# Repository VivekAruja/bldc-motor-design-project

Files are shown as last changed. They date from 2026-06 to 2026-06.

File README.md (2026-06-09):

# Brushless DC Motor Design Project

## Overview

This project presents the design, CAD modelling, 3D printing, winding, assembly, and testing of a small brushless DC motor (BLDC). The motor was designed as a radial flux, three phase, six slot/eight pole outrunner BLDC motor using SOLIDWORKS, 3D printed parts, permanent magnets, copper windings, and an electronic speed controller.

The goal of the project was to complete the full motor design workflow from theory to physical implementation. This included selecting motor specifications, performing design calculations, modelling the stator and rotor in SOLIDWORKS, exporting STL files, assembling the motor, winding the stator, and testing the final prototype.

## Final Technical Report

The full technical report is available here:

[Brushless DC Motor Design Project Report](report/BLDC_Motor_Project_Report.pdf)

## Project Motivation

Brushless DC motors are widely used in electric vehicles, drones, robotics, fans, pumps, and other electromechanical systems because they offer high efficiency, low maintenance, and reliable operation compared with brushed DC motors.

This project was built to answer one main question:

**Can a small custom BLDC motor be designed, fabricated, wound, assembled, and tested using 3D printed components and available lab materials?**

The project demonstrates the complete workflow:

Motor specifications
→ analytical calculations
→ SOLIDWORKS CAD modelling
→ STL export
→ 3D printing
→ stator winding
→ physical assembly
→ ESC testing
→ performance evaluation

## Tools and Technologies

* SOLIDWORKS
* 3D printing
* STL modelling
* BLDC motor design
* Electronic speed controller testing
* Copper winding
* Neodymium magnets
  
## Repository Structure

```text
bldc-motor-design-project/
│
├── assembly/
│   └── full motor assembly files and screenshots
│
├── images/
│   └── project images used for the README and report
│
├── parts/
│   └── SOLIDWORKS part files
│
├── report/
│   ├── main.tex
│   ├── BLDC_Motor_Project_Report.pdf
│   └── figures/
│
├── stl_exports/
│   ├── Rotor.STL
│   ├── StatorBottom.STL
│   └── StatorTop.STL
│
└── README.md
```

## Design Objectives

The main design objectives were:

* Design a small BLDC motor within the required size constraint.
* Use a six slot/eight pole electromagnetic layout.
* Create a radial flux outrunner motor design.
* Model the stator and rotor in SOLIDWORKS.
* Export the rotor and stator parts as STL files for 3D printing.
* Wind the stator using a three phase ABC winding scheme.
* Assemble the motor using the shaft, bearings, magnets, rotor, stator, and test base.
* Test the motor using an electronic speed controller.

## Motor Specifications

| Parameter | Value |
| --- | --- |
| Motor type | Radial flux outrunner BLDC |
| Number of phases | 3 |
| Stator teeth | 6 |
| Rotor poles / magnets | 8 |
| Winding scheme | ABC |
| Connection type | Wye / Star |
| Rated torque | 0.075 N·m |
| Rated speed | 2000 RPM |
| Rated voltage | 12 V |
| Estimated rated current | 1.31 A |
| Target air gap | 2 mm |
| Stator outer diameter | 61 mm |
| Rotor inner diameter | 65 mm |
| Rotor outer diameter | 71 mm |
| Axial stack length | 30 mm |
| Calculated turns per tooth | 17 turns |
| Actual turns per tooth | 8 turns |

## CAD Design

The motor was modelled in SOLIDWORKS using separate stator and rotor parts. The design focused on motor geometry, shaft alignment, bearing support, magnet placement, 3D printability, and assembly fit.

### Stator Design

The stator was designed with six teeth for a three phase winding layout. The stator includes a central shaft hole, bearing pockets, and a square mounting boss to fit the course test stand.

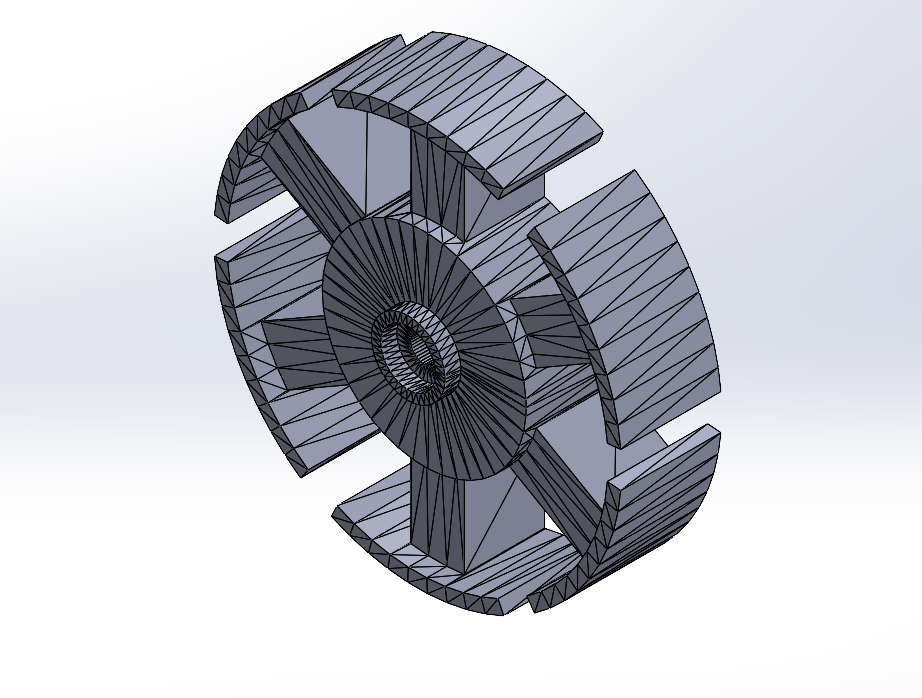
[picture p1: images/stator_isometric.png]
Stator CAD Model


### Rotor Design

The rotor was designed as an outrunner can with eight internal magnet pockets. The rotor surrounds the stator, allowing the permanent magnets to rotate around the wound stator teeth.

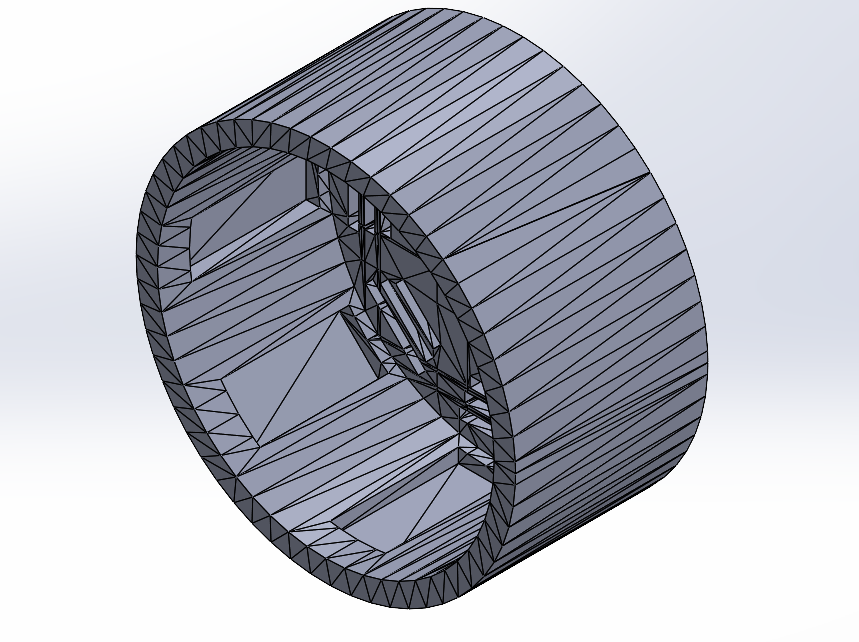
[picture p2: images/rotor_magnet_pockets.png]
Rotor Magnet Pockets


### Full Assembly

The full assembly was created in SOLIDWORKS to verify that the rotor and stator were aligned correctly and that the final geometry matched the intended outrunner BLDC design.

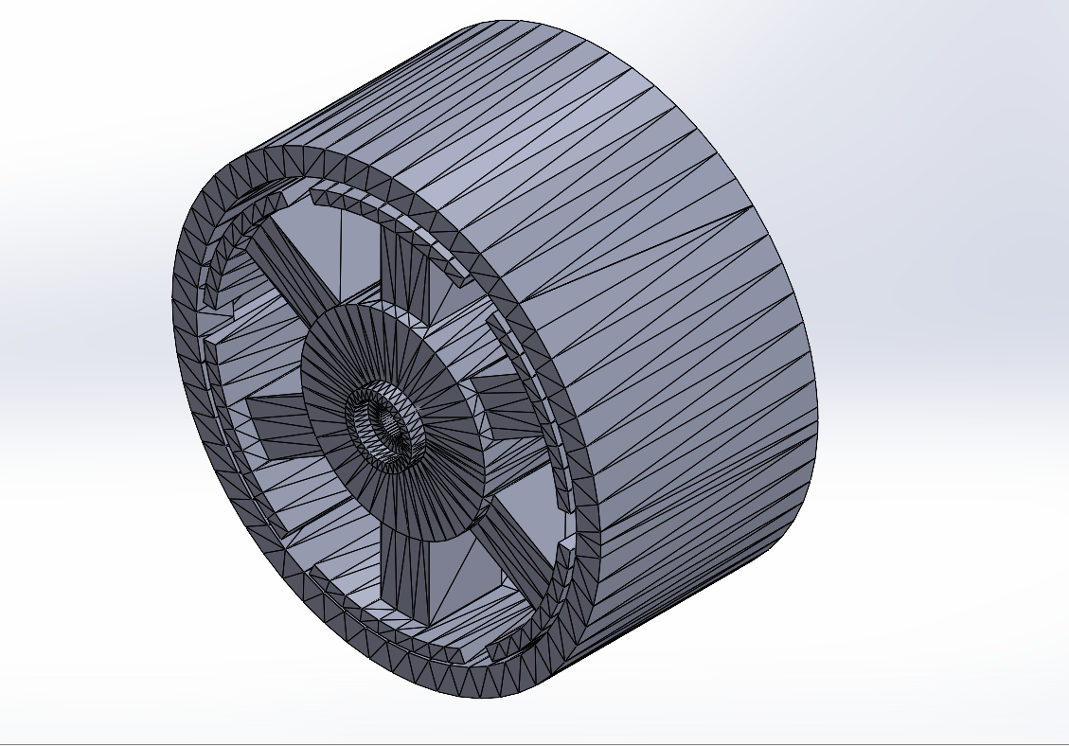
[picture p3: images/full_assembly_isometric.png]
Full BLDC Motor Assembly


## 3D Printing and Fabrication

The stator and rotor parts were exported as STL files and 3D printed. The exported files included:

* `Rotor.STL`
* `StatorBottom.STL`
* `StatorTop.STL`

The stator was split into top and bottom printed sections to improve manufacturability and simplify assembly around the shaft and bearing features. After printing, the parts were checked for fit, clearance, and alignment.

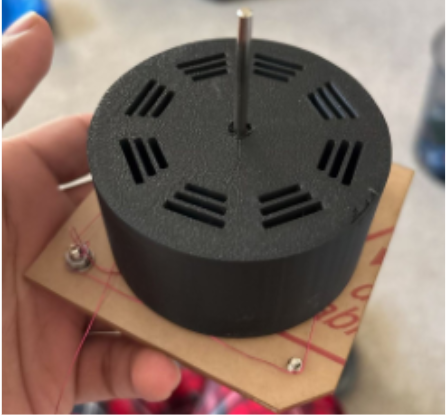
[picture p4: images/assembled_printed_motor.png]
Assembled 3D Printed Motor


## Winding and Assembly

The stator was wound using an ABC three phase winding arrangement with a wye connection. The calculated design required approximately 17 turns per tooth, but the final physical motor used 8 turns per tooth because the available wire gauge and slot space limited the number of turns that could be physically wound.

Eight N52 neodymium magnets were inserted into the rotor pockets to create the eight pole rotor field. The printed stator, rotor, shaft, bearings, magnets, and test base were then assembled into the final motor prototype.

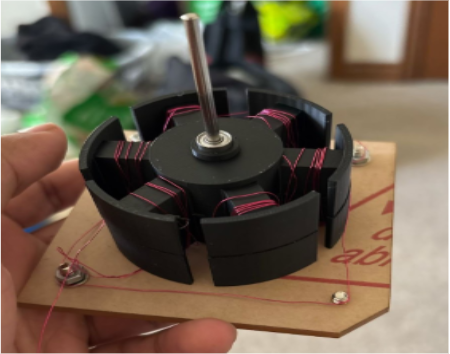
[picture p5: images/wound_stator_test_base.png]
Wound Stator Assembly


## Design Calculations

The main design calculations included:

* Angular velocity
* Mechanical output power
* Estimated rated current
* Flux density at the stator surface
* Number of teeth per phase
* Required winding turns per tooth

The rated speed was selected as 2000 RPM. The angular velocity was calculated as:

```text
ω = 2πN / 60
ω = 209.4 rad/s
```

The mechanical power was calculated using:

```text
P = τω
P = 0.075 × 209.4
P = 15.7 W
```

The estimated rated current was calculated using:

```text
I = P / V
I = 15.7 / 12
I = 1.31 A
```

The calculated number of turns per tooth was approximately 17 turns. The final motor used 8 turns per tooth due to physical slot space and wire gauge constraints.

## Testing Methodology

The motor was tested using an electronic speed controller, power supply, and control input. Before testing, the following checks were performed:

* Rotor clearance around the stator
* Shaft and bearing alignment
* Magnet placement
* Winding condition
* Phase wire connections
* Supply voltage limit

The motor response was evaluated based on whether it could start, whether it could sustain rotation, whether the rotor rubbed against the stator, and whether the ESC appeared to drive the motor phases correctly.

## Results

The final motor fit within the required size constraint and was successfully assembled using the 3D printed rotor and stator components. The motor responded to the electronic speed controller and produced slight rotational motion, but it did not sustain continuous independent rotation.

The main successful outcomes were:

* Completed BLDC motor design calculations
* Created stator and rotor CAD models in SOLIDWORKS
* Exported printable STL files
* 3D printed the motor components
* Wound the stator using a three phase winding layout
* Assembled the motor with shaft, bearings, rotor, stator, and magnets
* Tested the motor with an ESC

## Key Findings

The main findings were:

* The six slot/eight pole outrunner layout was appropriate for the project requirements.
* The motor geometry was successfully modelled and assembled.
* The physical prototype fit within the required size envelope.
* The actual air gap was larger than the design target, reducing magnetic coupling.
* The final winding count was lower than the calculated value because of slot space and wire gauge limitations.
* Mechanical friction and alignment issues reduced the available starting torque.
* Correct calculations alone do not guarantee strong physical performance because manufacturing tolerances and assembly quality strongly affect motor behaviour.

## Limitations

This project had several limitations:

* The stator and rotor were 3D printed using plastic rather than laminated ferromagnetic steel.
* The actual air gap was larger than the target design value.
* The motor used 8 turns per tooth instead of the calculated 17 turns per tooth.
* Magnet placement and winding were completed manually.
* Testing was mainly observational.
* The project did not include quantitative measurements of torque, no load speed, phase current, back EMF, or efficiency.

## Future Work

Future improvements could include:

* Reducing the rotor stator air gap.
* Redesigning the stator slots to allow more copper turns.
* Using thinner magnet wire to reach the calculated winding count.
* Improving magnet pocket tolerances and magnet retention.
* Improving shaft and bearing alignment.
* Reducing mechanical friction.
* Measuring phase resistance, current, no load speed, back EMF, torque, and efficiency.
* Comparing the 3D printed prototype with a design using laminated steel stator material.

## Lessons Learned

This project showed that BLDC motor design is not only a calculation problem. Physical performance depends heavily on manufacturing tolerance, winding feasibility, air gap control, magnet placement, bearing alignment, and assembly quality.

The project was successful as a full engineering design exercise because it connected theory, CAD modelling, fabrication, winding, assembly, testing, and performance analysis into one complete electromechanical system.

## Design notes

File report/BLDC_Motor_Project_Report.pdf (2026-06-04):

## Brushless DC Motor Design Project

Design, CAD Modelling, 3D Printing, Winding, Assembly, and Testing of a Low Power BLDC Motor

Vivek Aruja

December 10, 2025

Abstract

This project covers the design, modelling, fabrication, winding, assembly, and testing of a small brushless DC motor. The objective was to design a radial flux, three phase, six slot/eight pole outrunner BLDC motor that satisfied the course size and electrical constraints and demonstrated the full motor design workflow from calculations to physical testing. The motor targets a rated torque of 0.075 N ∗ m, a rated speed of 2000 RPM, a rated voltage of 12 V, and an estimated rated current of 1.31 A. The six slot/eight pole electromagnetic layout avoids a one to one teeth to poles relationship to reduce cogging.

The design process began with motor specification selection, analytical calculations, and SOLIDWORKS modelling. The stator was modelled with a 61 mm outer diameter, six teeth, a central shaft hole, bearing pockets, and a square mounting boss for the test stand. The rotor was modelled as an outrunner can with a 65 mm inner diameter, a 71 mm outer diameter, eight magnet pockets, a shaft clearance hub, and ventilation openings. Both files were exported as STL files and 3D printed. After fabrication, the stator was wound using an ABC winding scheme in a wye connection. The calculated design required approximately 17 turns per tooth; the final physical motor used 8 turns per tooth because slot space and wire gauge constraints prevented achieving the full count.

Testing confirmed that the motor responded to the electronic speed controller and produced slight rotational motion, but the motor did not sustain continuous independent rotation. The main limiting factors were an actual air gap larger than the design target, fewer winding turns than calculated, magnet placement inconsistencies, and mechanical friction from the shaft and bearings. The project completed the full process of designing and building a custom BLDC motor and exposed the practical gap between theoretical motor design and physical electromechanical construction.

## Contents

1 | Introduction | 3
2 | Technical Background | 4
3 | Design Requirements and Constraints | 5
4 | Selected Design Parameters | 6
5 | Design Calculations | 7
6 | CAD Design | 10
7 | 3D Printing and Fabrication | 14
8 | Winding and Motor Assembly | 15
9 | Testing Methodology | 17
10 Results | 18
11 Discussion | 19
12 Limitations | 20
13 Future Work | 20
14 Conclusion | 21
References | 22

### 1 Introduction

Brushless DC motors convert electrical energy into mechanical rotation using permanent magnets, stator windings, and electronic commutation. A BLDC motor uses no brushes or mechanical commutator. An electronic speed controller energizes the motor windings by switching motor phases in sequence. A typical three phase BLDC motor achieves improved reliability, lower maintenance, reduced sparking, and better efficiency compared with brushed motor designs.

The objective of this project was to design and build a small BLDC motor that satisfied the course requirements and remained manufacturable using 3D printed parts and available lab components. The motor had to fit within the specified physical size envelope and use the provided shaft, bearings, magnets, copper wire, and test stand.

A radial flux, three phase, six slot/eight pole outrunner BLDC motor was selected. The outrunner layout places the rotor around the stator, increasing the effective rotating radius and improving low speed torque. The six slot/eight pole combination avoids a one to one relationship between stator teeth and rotor poles, which reduces cogging and prevents repeated full alignment between the rotor magnets and stator teeth.

The project followed the engineering workflow below:

Specification selection → analytical calculations → CAD modelling → STL export → 3D printing → winding → assembly → ESC testing

The main design goals were to:

- Design a motor that fits within the 74 mm × 74 mm × 44 mm size constraint.
- Use a six slot/eight pole electromagnetic layout.
- Calculate a realistic number of winding turns per tooth.
- Create manufacturable stator and rotor models in SOLIDWORKS.
- Export STL files suitable for 3D printing.
- Assemble the motor using lab provided shaft, bearings, magnets, and copper wire.
- Test the motor using an electronic speed controller.

### 2 Technical Background

### 2.1 BLDC Motor Operation

A brushless DC motor consists of a stationary stator and a rotating rotor. The stator carries wound copper coils and the rotor carries permanent magnets. Current flowing through the stator windings produces magnetic fields that interact with the rotor magnets and generate torque.

Since a BLDC motor contains no brushes, phase switching must be performed electronically. An electronic speed controller energizes selected motor phases in a controlled sequence. In a three phase BLDC motor, two phases carry current at a time and the third phase floats or is monitored depending on the control strategy. This creates a rotating magnetic field that pulls the rotor into motion.

### 2.2 Outrunner Motor Layout

In an outrunner BLDC motor, the rotor forms an outer rotating shell around the stationary stator. The permanent magnets attach to the inside surface of the rotor and the copper windings sit around the stator teeth. This configuration increases the radius at which magnetic force is applied, improving torque production at low to moderate speeds.

The selected motor uses a radial flux outrunner layout. Magnetic flux crosses the radial air gap between the rotor magnets and stator teeth. The air gap is a critical design parameter because increasing the distance between magnets and windings reduces the magnetic field acting on the stator teeth.

### 2.3 Slots, Teeth, Poles, and Cogging

The stator teeth provide the locations for winding the copper coils. The rotor poles correspond to the permanent magnets installed around the rotor. The selected design used six stator teeth and eight rotor poles.

The teeth to poles ratio is:

Ts : Pr = 6 : 8 | (1)

This ratio is not one to one because equal stator to rotor alignment increases cogging and makes the motor startup more difficult. The six slot/eight pole layout ensures the teeth and magnets do not repeatedly align in a symmetrical locking position.

### 3 Design Requirements and Constraints

The motor design was constrained by course requirements and practical manufacturing limits.

### 3.1 Electrical Requirements

The electrical design targets the following values:

- Rated voltage: 12 V
- Rated torque: 0.075 N ∗ m
- Rated speed: 2000 RPM
- Estimated current: 1.31 A
- Three phase winding
- Wye connection
- Compatibility with an electronic speed controller

A wye connection reduces the current per phase compared with a delta connection, making the design more suitable for the available wire and course testing setup.

### 3.2 Mechanical Requirements

The mechanical design satisfies the following requirements:

- Fits within a 74 mm × 74 mm × 44 mm bounding box.
- Uses 3D printed stator and rotor components.
- Fits the provided shaft and bearing geometry.
- Fits the course test stand.
- Provides clearance between the rotating rotor and stationary stator.
- Provides sufficient slot space for the windings.
- Allows magnet pockets to hold the rotor magnets securely.

### 3.3 Manufacturing Requirements

The stator and rotor were exported as STL files for 3D printing. The design therefore accounts for printability, tolerances, flat surfaces, support requirements, and clearance for post print assembly.

### 4 Selected Design Parameters

Table 1 summarizes the main motor parameters used in the design.

Table 1: Selected BLDC motor design parameters.

Parameter | Value | Reason / Note
Motor type | Radial flux outrunner
| BLDC | Selected for low speed torque
| | potential
Number of phases | 3 | Standard BLDC configuration
Stator teeth | 6 | Multiple of three for three
| | phase winding
Rotor poles / magnets | 8 | Avoids one to one teeth to
| | poles ratio
Winding scheme | ABC | Simple three phase winding
| | layout
Connection type | Wye / Star | Reduces current per phase
Rated torque | 0.075 N ∗ m | Target design torque
Rated speed | 2000 RPM | Moderate speed target
Rated voltage | 12 V | Within low voltage testing
| | range
Magnet grade | N52 neodymium | High residual flux density
Residual flux density, Br | 1.42 T | Used for surface flux estimate
Magnet thickness, t | 0.002 m | Matches rotor pocket depth
Air gap, g | 0.002 m target | Required clearance between
| | rotor and stator
Tooth wall thickness, k | 0.002 m | Plastic wall thickness in flux
| | path
Stator radius, R | 0.0305 m | Used in torque turns calcula-
| | tion
Axial stack length, L | 0.030 m | Selected motor axial length
Calculated turns per tooth | 17 turns | From design equation
Actual turns per tooth | 8 turns | Limited by slot space and wire
| | thickness

### 5 Design Calculations

### 5.1 Angular Velocity

The rated speed was selected as 2000 RPM. Angular velocity was calculated using:

ω =

2πN
60

(2)

where N is the speed in RPM. Substituting the selected speed:

ω =

2π(2000)
60

(3)

ω = 209.4 rad/s | (4)

### 5.2 Mechanical Power

Mechanical output power was calculated using:

Pm = τω | (5)

where τ is torque and ω is angular velocity. At a selected torque of 0.075 N m:

Pm = (0.075)(209.4) | (6)
Pm = 15.7W | (7)

### 5.3 Rated Current

Motor current was estimated from mechanical power and rated voltage:

I =

Pm
V

(8)

Substituting the calculated power and selected voltage:

I =

15.7
12

(9)

I = 1.31 A | (10)

### 5.4 Flux Density at the Stator Surface

The estimated flux density at the stator surface was calculated using:

Ba = Br

t
t + g + k

(11)

where Br is the residual flux density of the magnet, t is magnet thickness, g is the air gap, and k is tooth wall thickness. The selected values were:

Br = 1.42 T, | t = 0.002 m, | g = 0.002 m, | k = 0.002 m | (12)

Therefore:

Ba = 1.42
| | 0.002

0.002 + 0.002 + 0.002
(13)
Ba = 0.473 T | (14)

This equation shows the importance of air gap control. An actual air gap larger than the design value reduces the flux density at the stator surface and lowers the torque the motor can produce.

### 5.5 Number of Teeth per Phase

The number of teeth per phase was calculated using:

n =

Total number of stator teeth
Number of phases | (15)

For six teeth and three phases:

n =

6
3
= 2 | (16)

### 5.6 Turns per Tooth

The required number of turns per tooth was estimated using:

N =

τ
4nBaLRI

(17)

where N is the turns per tooth, τ is torque, n is teeth per phase, Ba is flux density at the stator surface, L is axial stack length, R is stator radius, and I is current.

Substituting the selected values:

N =

0.075
4(2)(0.473)(0.030)(0.0305)(1.31) | (18)
N = 16.5 ≈ 17 turns per tooth | (19)

The calculated value falls within the practical target range of 5 to 50 turns per tooth. The final physical motor used 8 turns per tooth because the available wire gauge and stator slot volume could not accommodate the full calculated number.

### 6 CAD Design

The motor was modelled in SOLIDWORKS using separate stator and rotor parts. The CAD design covers electromagnetic geometry, shaft alignment, bearing support, magnet pockets, and manufacturability through 3D printing.

### 6.1 Stator Design

The stator was designed first. A circle with a radius of 30.5 mm defines the outer radius of the stator teeth, giving a total stator diameter of 61 mm. A smaller concentric circle with a radius of 20 mm defines the inner hub and back iron region.

A single tooth profile was created with radial geometry and a tooth width of approximately 6 mm. A circular pattern with six instances was used to complete the tooth array. The stator was extruded to an axial length of 30 mm.

A square mounting boss of 15 mm × 15 mm was added to the bottom face of the stator. This boss fits the stator into the course test stand and prevents the stator from rotating during motor operation.

A central shaft hole was cut with a radius of 1.5 mm for the 3 mm shaft. Bearing pockets were cut into the stator to locate the bearings and improve shaft alignment.

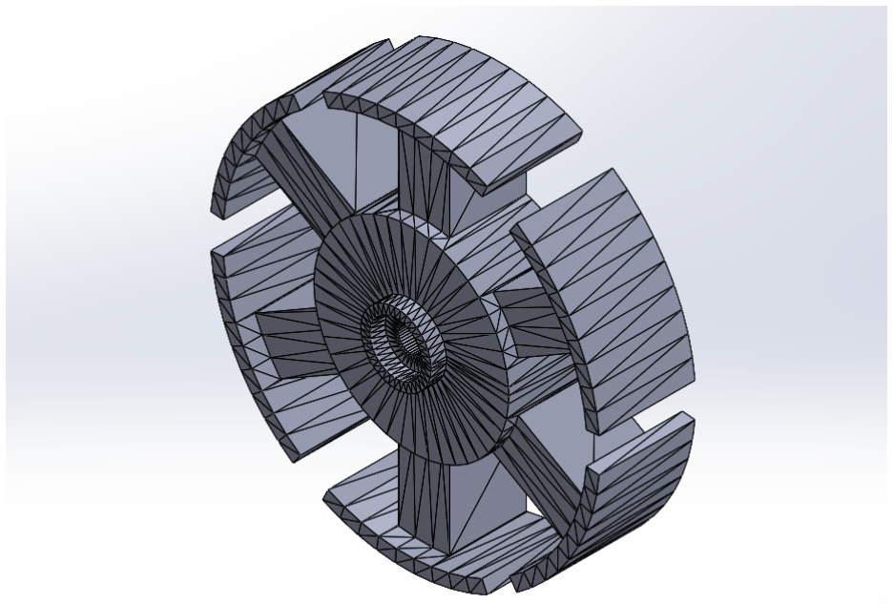
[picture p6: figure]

Figure 1: Isometric view of the six slot outrunner stator CAD model

### 6.2 Rotor Design

The rotor was designed as an outrunner can. To maintain a target air gap of 2 mm, the inside radius of the rotor was set as:

Rrotor, inner = Rstator + g = 30.5 + 2.0 = 32.5 mm | (20)

This gives an inner diameter of 65 mm. The outer radius of the rotor was set to 35.5 mm, giving an outer diameter of 71 mm. The annular rotor wall was extruded to an axial length of 30 mm.

A 3 mm thick cap closes the top of the rotor. Hub cylinders near the shaft region improve strength at the shaft and bearing interface. A shaft clearance hole with radius 1.65 mm passes through the rotor hub to allow a sliding fit.

Eight rectangular magnet pockets were cut into the inside surface of the rotor and patterned around the rotor to create the eight pole layout. The magnet pocket depth matches the magnet thickness of approximately 2 mm. Ventilation slots in the rotor cap reduce mass and allow air flow near the windings.


Figure 2: Rotor CAD model with eight internal magnet pockets

### 6.3 SOLIDWORKS Assembly

After modelling the individual parts, a full assembly was created in SOLIDWORKS. The stator bottom, stator top, and rotor were inserted into a SOLIDWORKS assembly file. The stator components were aligned to form the complete stationary structure and the rotor was positioned concentrically around the stator to represent the final outrunner motor geometry.

The assembly confirmed the relative position of the rotor and stator and produced documentation screenshots for the final report. Because the available geometry was based on STL mesh files, the assembly served as a visual and documentation model rather than a fully parametric SOLIDWORKS assembly.

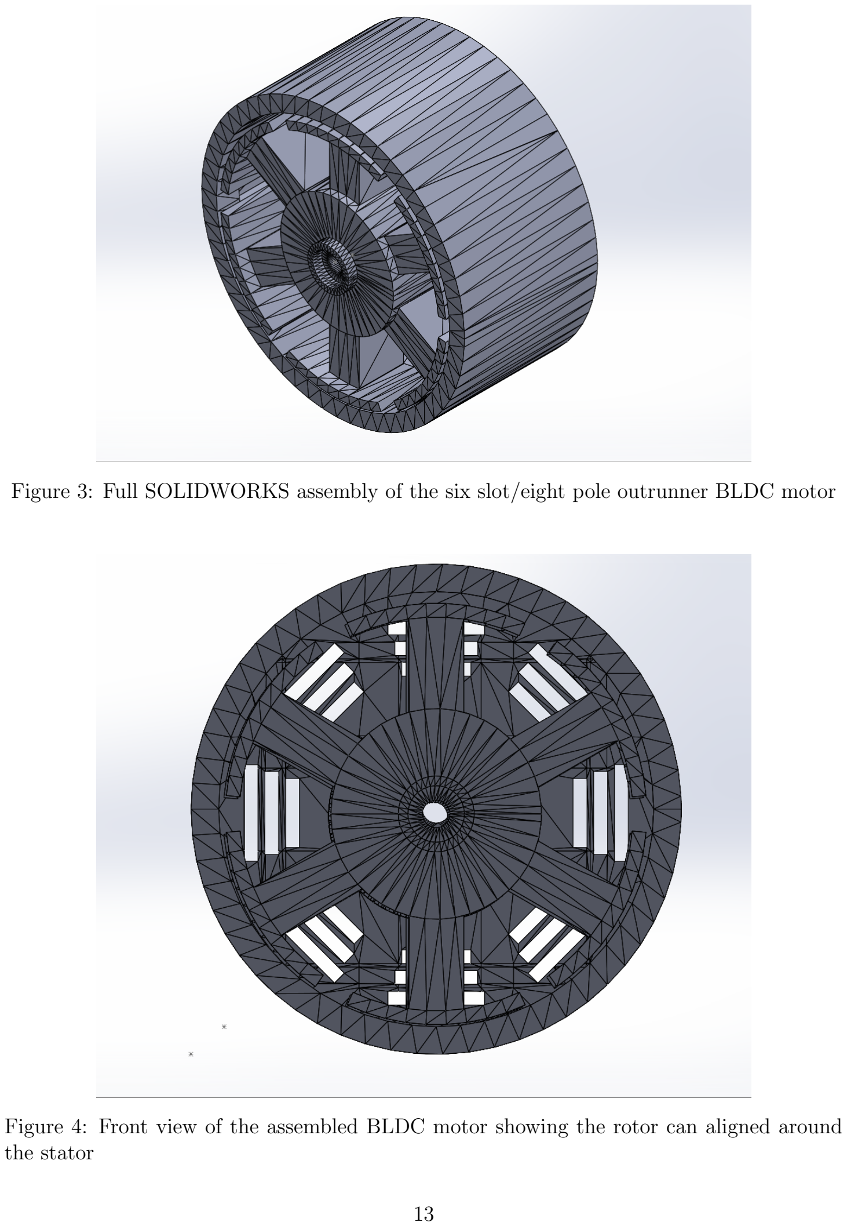
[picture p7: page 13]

Figure 3: Full SOLIDWORKS assembly of the six slot/eight pole outrunner BLDC motor

Figure 4: Front view of the assembled BLDC motor showing the rotor can aligned around the stator

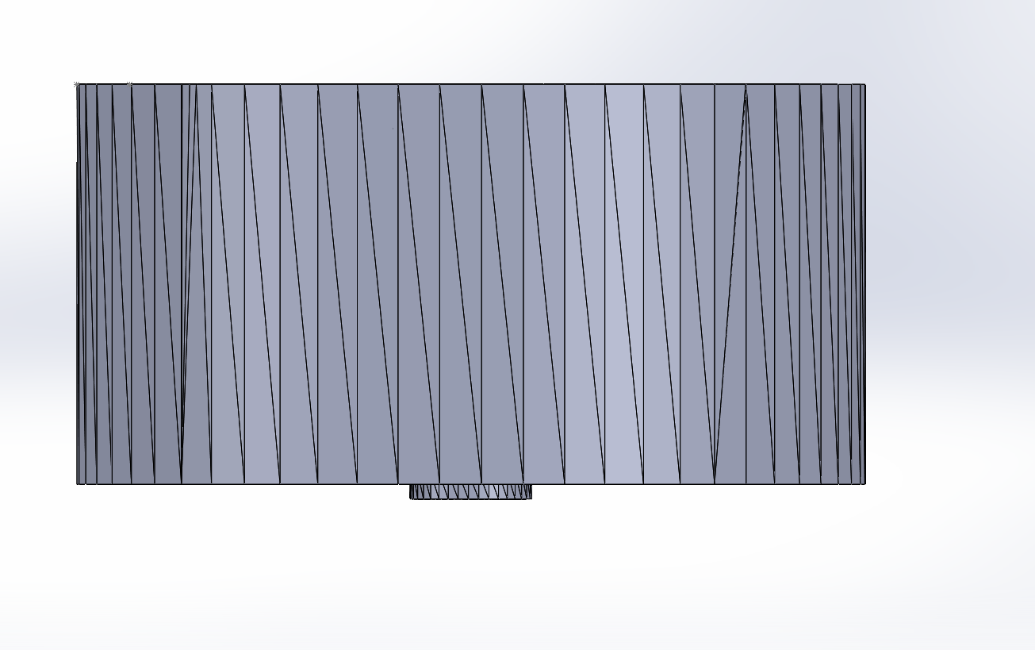
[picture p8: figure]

Figure 5: Top view of the rotor and stator alignment in the BLDC motor assembly

### 7 3D Printing and Fabrication

After completing the CAD models, the stator and rotor were exported as STL files for 3D printing. The exported files were:

- Rotor.STL
- StatorBottom.STL
- StatorTop.STL

The stator was split into top and bottom printed sections to improve manufacturability and simplify the assembly around the bearing and shaft features. The rotor was printed as an outrunner can with integrated magnet pockets and ventilation slots.

After printing, the parts were inspected for fit and clearance. The shaft was installed through the central hole and the rotor was placed around the stator. The printed assembly fit within the size constraint, but the actual air gap exceeded the target design gap because of 3D printing tolerance and the need to prevent rubbing between the rotating and stationary parts.


Figure 6: Assembled 3D printed BLDC motor with shaft installed

### 8 Winding and Motor Assembly

### 8.1 Winding Scheme

The selected winding scheme uses an ABC three phase arrangement with a wye connection. The wye connection reduces the phase current compared with a delta connection, making it more suitable for the available wire and low current test setup.

The calculated design required approximately 17 turns per tooth. The final motor used 8 turns per tooth because the available lab wire was too thick to fit the full calculated turn count inside the stator slots. All windings were wound clockwise per the selected winding direction.

### 8.2 Magnet Installation

Eight N52 neodymium magnets were inserted into the rotor pockets. The magnets were arranged around the inside of the rotor to form the eight pole magnetic field. Correct magnet placement is important because uneven spacing or incorrect polarity creates unbalanced magnetic pull and reduces startup performance.

### 8.3 Physical Assembly

The printed stator was installed onto the test stand using the square mounting boss. The shaft and bearings were installed through the central axis and the rotor was mounted concentrically around the stator. The final assembly includes the wound stator, rotor, shaft, bearings, magnets, and base.


Figure 7: Stator assembly with wound coils installed on the test base

### 9 Testing Methodology

The motor was tested using an electronic speed controller, power supply, and control input. The ESC was connected to the three motor phase wires and attempted to start the motor using electronic commutation.

Before testing, the following checks were performed:

- The rotor was checked for free movement around the stator.
- The shaft and bearings were checked for alignment.
- The magnet pockets were inspected for magnet placement.
- The windings were inspected for loose wires or obvious shorts.
- The phase wires were connected to the ESC.
- The supply voltage was kept within the course voltage limit.

During testing, the motor response was observed. The main evaluation criteria were whether the motor could start, whether it could sustain rotation, whether the rotor contacted the stator, and whether the ESC detected and drove the motor phases correctly.

### 10 Results

Table 2 summarizes the final design and testing results.

Table 2: Final BLDC motor parameter summary.

Parameter | Value | Notes
Motor type | Radial flux outrunner | Three phase BLDC motor
Stator teeth | 6 | Compatible with three phase
| | winding
Rotor poles | 8 | Avoids T : P = 1
Winding scheme | ABC, wye | Selected to reduce phase
| | current
Magnet grade | N52 neodymium | Br = 1.42 T
Rated torque | 0.075 N ∗ m | Design target
Rated speed | 2000 RPM | Moderate speed target
Rated voltage | 12 V | Within voltage constraint
Mechanical power | 15.7W | From Pm = τω
Rated current | 1.31 A | From I = P/V
Target air gap | 0.002 m | Actual gap became larger after
| | printing
Stator radius | 0.0305 m | Used in turn calculation
Axial length | 0.030 m | 3D printable stack length
Flux density at stator | 0.473 T | From flux density equation
Calculated turns per tooth | 17 turns | From design equation
Actual turns per tooth | 8 turns | Limited by wire thickness and
| | slot space
Magnet thickness | 0.002 m | Matches rotor pocket depth
Size constraint | 74 mm × 74 mm ×
| 44 mm | Satisfied
Testing outcome | Partial rotation | Motor did not sustain
| | continuous operation

The final motor fit within the required size envelope and was assembled using the 3D printed rotor and stator components. The motor responded when connected to the ESC and produced slight rotational movement but did not sustain continuous independent rotation.

The design succeeded in completing the CAD model, exporting STL files, 3D printing, assembling with the shaft and bearings, and implementing the three-phase winding. The main performance limitations were the larger than target air gap, reduced actual turns per tooth, magnet placement variation, and friction in the shaft-bearing assembly.

### 11 Discussion

The final motor performance did not match the theoretical design calculations. The motor produced slight motion when the ESC attempted to start it but could not maintain continuous rotation. Several factors account for this outcome.

The first issue was the air gap between the rotor magnets and the stator teeth. The design target was approximately 2 mm. After 3D printing and physical assembly, the actual air gap exceeded the target value. The flux density equation depends on air gap thickness, so any increase in air gap reduces the magnetic field acting on the stator teeth. A weaker magnetic field produces less electromagnetic torque, making startup and sustained rotation more difficult.

The second issue was the reduced winding count. The calculation predicted approximately 17 turns per tooth, but only 8 turns per tooth could be wound using the available wire. The magnetic field produced by a coil depends on the number of turns and current, so reducing the turns reduced the available stator field strength. This lowered the torque and reduced the back EMF available to the ESC, making sensorless startup more difficult.

The third issue was magnet placement. The rotor pockets held the magnets, but small inconsistencies in spacing or alignment created uneven magnetic pull. This makes the rotor harder to start and increases vibration and cogging.

The fourth issue was mechanical friction. Even though the CAD assembly showed no interference, the printed parts, shaft, and bearings introduced real world tolerances. Slight misalignment or bearing resistance can consume a large portion of the available starting torque, particularly in a small motor with reduced winding turns.

The design approach was solid. The six slot/eight-pole layout was appropriate, the wye connected ABC winding was reasonable, and the motor fit within the size envelope. The gap between the calculation and the final result came from physical implementation constraints rather than from the overall concept.

### 12 Limitations

The project had several limitations.

First, the stator and rotor were 3D printed in plastic rather than manufactured with laminated ferromagnetic steel. A commercial BLDC motor uses magnetic steel laminations to guide flux through the stator. The plastic stator structure reduced the magnetic effectiveness of the design.

Second, the actual air gap was larger than the target value. A larger air gap reduced the magnetic coupling between the rotor magnets and stator windings and decreased torque production.

Third, the number of turns per tooth was lower than calculated. The calculated design required 17 turns per tooth, but the final motor used only 8 turns per tooth because of wire thickness and slot space limitations.

Fourth, testing was observational. The project did not include quantitative measurements of torque, no load speed, phase current, back EMF, or efficiency. Performance could only be evaluated based on whether the motor started and sustained rotation.

Fifth, magnet placement and winding were performed by hand. Manual assembly introduced small inconsistencies that affected the final motor behaviour.

### 13 Future Work

Future improvements should focus on increasing torque production and reducing mechanical losses.

The first improvement is reducing the air gap. A smaller, more consistent air gap increases the magnetic flux density at the stator surface and improves torque. Better print accuracy, a redesigned rotor stator clearance, and improved alignment features would achieve this.

The second improvement is increasing the available winding space. The stator slot geometry can be redesigned to accommodate more copper turns. Thinner magnet wire would allow the calculated 17 turns per tooth to be achieved.

The third improvement is tightening magnet alignment. Tighter rotor pockets, adhesive retention, and polarity markings would reduce magnet placement errors and improve rotor balance.

The fourth improvement is reducing mechanical friction. Better bearing alignment, a smoother shaft fit, and improved hub geometry would reduce startup resistance.

The fifth improvement is adding quantitative testing. Future testing should measure phase resistance, phase current, no load speed, startup current, back EMF, and torque. These measurements would allow the physical motor performance to be compared with the design calculations.

### 14 Conclusion

This project completed the full process of designing and building a custom brushless DC motor. A radial flux, three phase, six slot/eight pole outrunner BLDC motor was designed through analytical calculations, SOLIDWORKS CAD modelling, STL export, 3D printing, manual winding, assembly, and ESC based testing.

The design satisfied the main physical constraints and produced a manufacturable motor assembly. The stator and rotor were modelled, printed, assembled with the shaft and bearings, wound using an ABC wye configuration, and connected to an electronic speed controller.

The final motor produced slight rotational motion but did not sustain continuous independent operation. The main reasons were the larger than target air gap, the reduced actual winding count, magnet placement variation, and mechanical friction. These issues reduced the available torque and made ESC startup more difficult.

The project demonstrated that correct calculations alone do not guarantee physical performance. Motor performance depends on manufacturing tolerance, winding feasibility, air gap control, magnet placement, and mechanical alignment. The project was successful as an engineering design and learning exercise because it connected theory, CAD, fabrication, winding, assembly, and practical testing into one complete electromechanical system.

### References

1. T. A. Asad, BLDC Motor Design Tutorial #1, ECE 3332a, Western University.
2. T. A. Asad, BLDC Motor Design Tutorial #2, ECE 3332a, Western University.
3. T. A. Asad, BLDC Motor Design Tutorial #3, ECE 3332a, Western University.
4. T. A. Asad, BLDC Motor Design Tutorial #4, ECE 3332a, Western University.
5. T. A. Asad, BLDC Motor Design Tutorial #5, ECE 3332a, Western University.

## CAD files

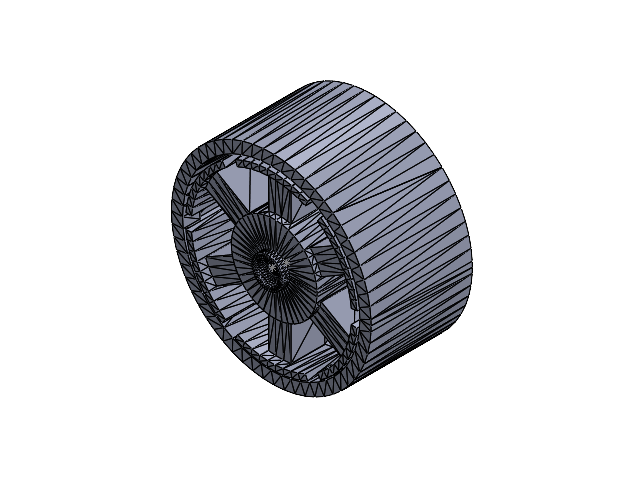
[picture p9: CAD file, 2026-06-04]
assembly/BLDC_Motor_Assembly.SLDASM
StatorBottom
Rotor
StatorTop

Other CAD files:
parts/StatorTop.SLDPRT
parts/StatorBottom.SLDPRT
parts/Rotor.SLDPRT
stl_exports/Rotor.STL
stl_exports/StatorBottom.STL
stl_exports/StatorTop.STL

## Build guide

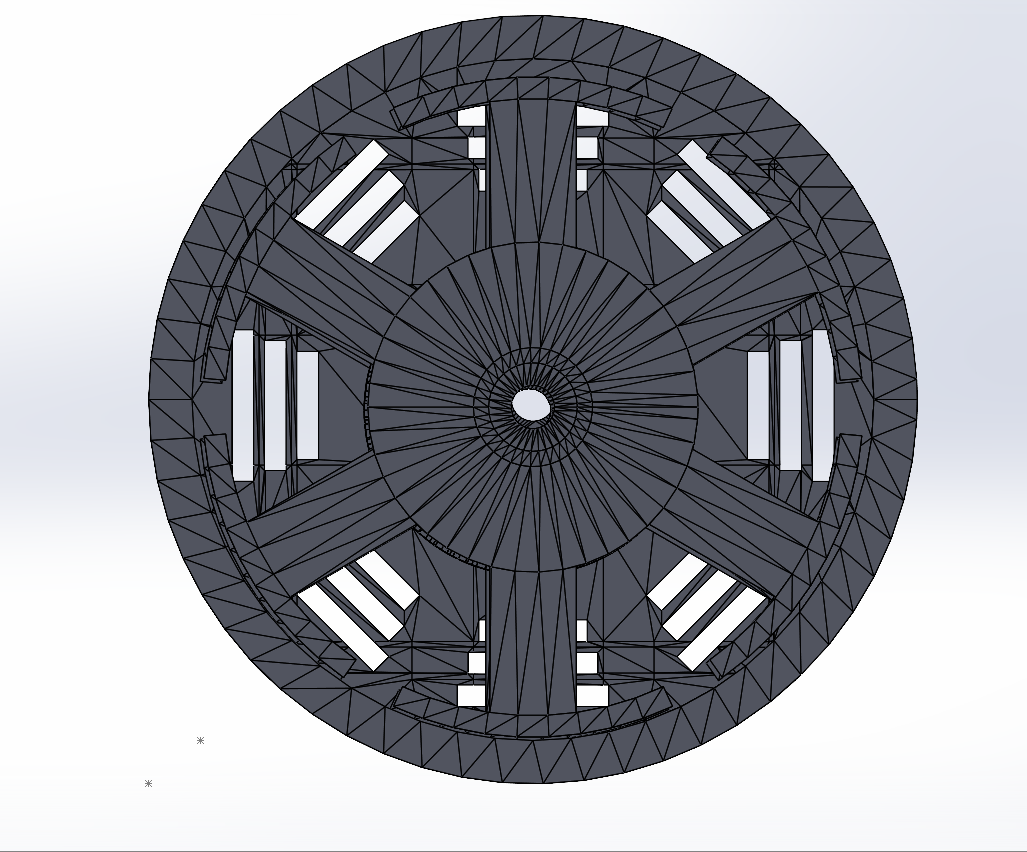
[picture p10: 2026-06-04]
images/full_assembly_front_view.png
